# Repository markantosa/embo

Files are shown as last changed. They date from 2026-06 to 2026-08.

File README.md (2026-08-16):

# EMBO — Embolization Particle Sizing System

> SUTD 30.007 Engineering Design Innovation | Team EMBO | Week 13 of 13

EMBO is a closed-loop medical device that automates and quality-controls the preparation of gelatin foam embolic agents for interventional radiology procedures. It is the first device of its kind to measure and control particle size during embolic agent preparation in real time.

| | |
|:---:|:---:|
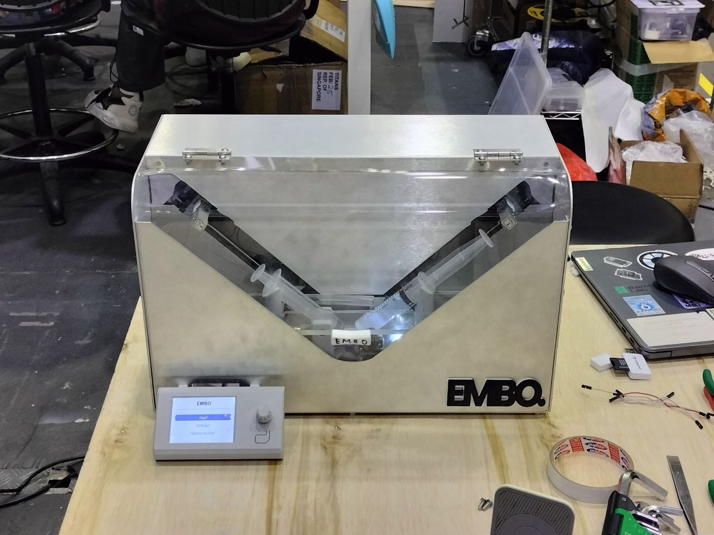
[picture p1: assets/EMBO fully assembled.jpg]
EMBO fully assembled
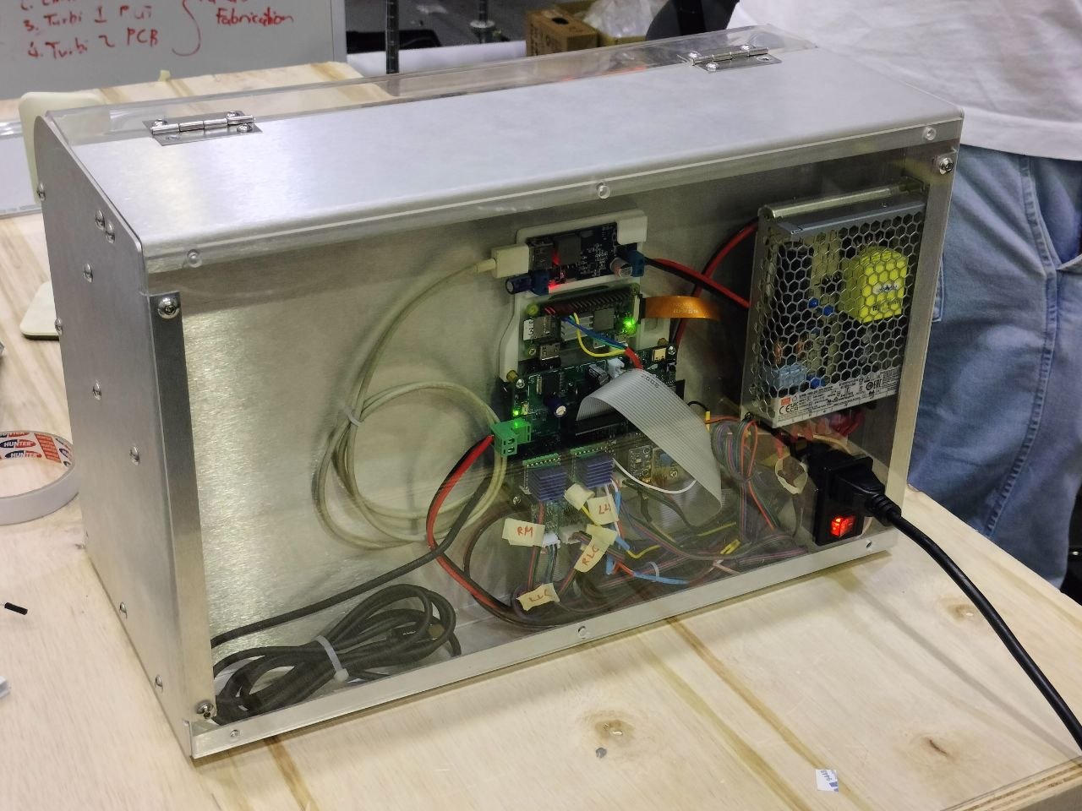
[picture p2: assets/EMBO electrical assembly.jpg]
EMBO electrical assembly
|  |  |
| *Fully assembled device* | *Electrical assembly* |

**CAD renders**

| Isometric | Front | Sheet-metal enclosure |
|:---:|:---:|:---:|
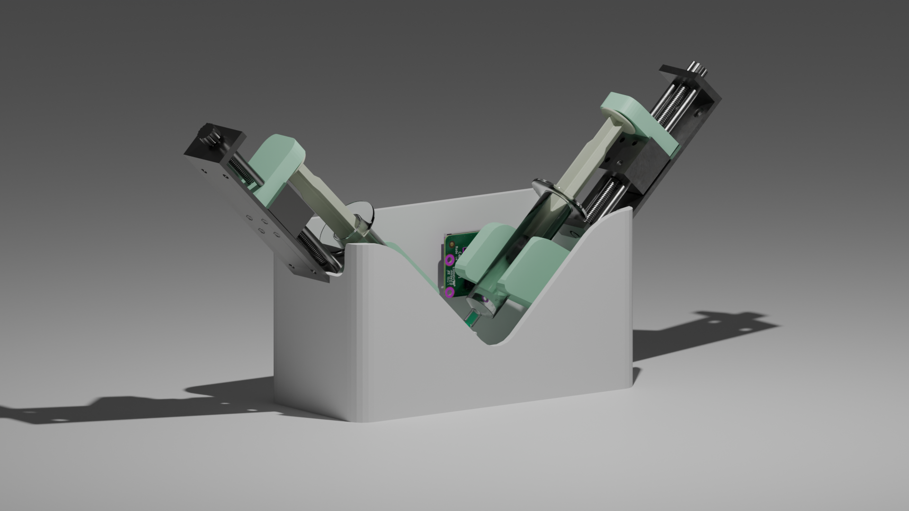
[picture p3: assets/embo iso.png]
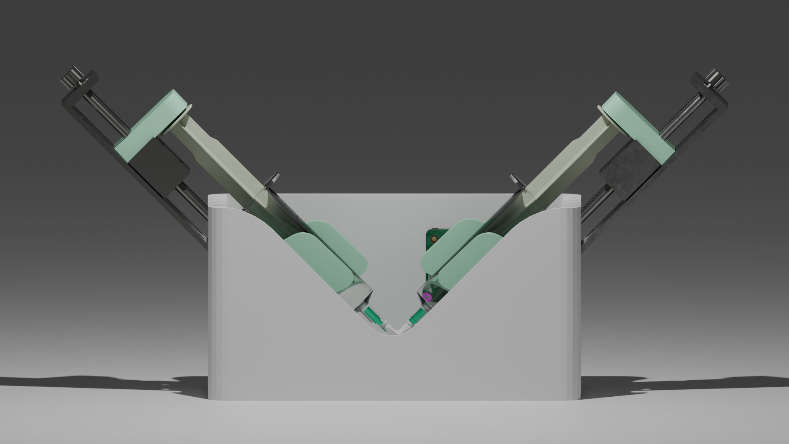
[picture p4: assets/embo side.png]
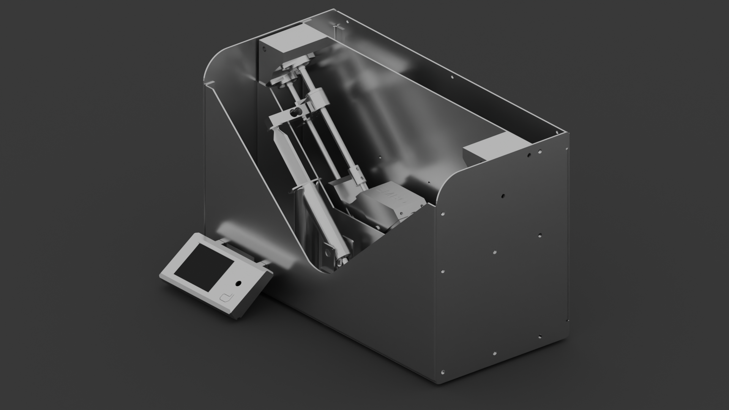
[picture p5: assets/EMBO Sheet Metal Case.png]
|  |  |  |
| *First concept render (Blender)* | *First concept render (Blender)* | *CAD (Fusion 360)* |

---

## The Problem

Embolization procedures use tiny gelatin foam particles (embolic agents) to deliberately block blood vessels — treating tumours, fibroids, and bleeding. Before every procedure, a clinician manually prepares a particle slurry by pumping two syringes back and forth until the mixture reaches a "pudding consistency." There is no measurement, no standard, and no quality check. Two clinicians doing this side by side produce slurries with completely different particle size distributions. Particle size directly affects clinical outcomes: wrong sizes can cause tissue death in unintended areas or fail to block the target vessel.

**No device currently exists to measure or control particle size during this preparation step.** Gelfoam has been used since the 1970s with the preparation method unchanged.

---

## What EMBO Does

EMBO replaces manual syringe pumping with a controlled, sensor-guided system that:

1. **Automates mixing** — two stepper motors drive syringe plungers back and forth with precise speed, stroke, and cycle control
2. **Measures particle size** using two independent sensing modalities:
   - **Ultrasound attenuation (UAS)** — a 1 MHz acoustic signal chain measures how much sound energy the slurry absorbs; larger particles attenuate more. This is the **closed-loop** measurement the mixing stop condition actually runs on.
   - **Computer vision (verification only)** — a Raspberry Pi Zero 2W + OV9281 global-shutter mono camera captures a frame on demand and runs it through a Roboflow-hosted instance-segmentation model, reporting median particle size and IQR plus a segmentation-blob-annotated photo. This is an **optional, operator-triggered check**, not a continuous control input — see "Sensing System" below for why.
3. **Stops automatically** when the target particle size is reached, using a closed-loop control scheduler on the ESP32-S3 driven by the UAS delta-voltage size equation, adjusting stroke-by-stroke based on live sensor feedback. The target is adjustable per procedure (50–1000 µm, set via the touchscreen/encoder), since the ideal size depends on which vessels are being treated.

---

## System Architecture

```
┌─────────────────────────────────────────────────────────────────┐
│                        EMBO Device                              │
│                                                                 │
│  ┌──────────────────┐          ┌──────────────────────────────┐ │
│  │ Raspberry Pi     │◄─UART──►│     ESP32-S3 MCU Board       │ │
│  │ Zero 2W          │          │                              │ │
│  │  - Roboflow      │          │  - Scheduler control loop    │ │
│  │    hosted CV     │          │    (UAS delta-V closed loop) │ │
│  │    (on-demand)   │          │  - 2× TMC2209 motor drivers  │ │
│  │  - Particle size │          │  - UAS signal chain          │ │
│  │    + annotated   │          │  - ILI9341 TFT UI (LovyanGFX)│ │
│  │    photo         │          │  - BLE debug (NimBLE)        │ │
│  │  - OV9281 CSI    │          │                              │ │
│  │    mono camera   │          │                              │ │
│  └──────────────────┘          └──────────────────────────────┘ │
│           │                             │           │            │
│           ▼                             ▼           ▼            │
│    [Camera + LED]              [Stepper motors] [UAS Transducers]│
│    [Backlight panel]           [Limit switches] [SMA connectors] │
└─────────────────────────────────────────────────────────────────┘
```

### Particle Size Model

Mixing follows first-order breakage kinetics:

```
D(N) = D_min + (D₀ − D_min) × e^(−kN)
```

Where `N` is stroke count, `k` is a shear constant (measured empirically), `D₀` is initial particle size, and `D_min` is the minimum achievable size. The mixing scheduler uses live measurements of `D(N)` (via the UAS delta-V equation) to decide when to stop.

---

## Repository Structure

```
EMBO/
├── README.md
├── .gitignore
│
├── docs/                              # Design documents and briefs
│   ├── EMBO_Project_Overview.md       # Project context — public/general audience
│   ├── EMBO_PCB_Design_Brief_v3_4.txt # Complete electrical design spec (current)
│   ├── EMBO_PCB_Design_Brief_v3_4.docx / .pdf
│   ├── EMBO_PCB_Design_Brief_v2.51.txt# Superseded — kept for reference
│   └── EMBO_Pinout_Cheatsheet.txt     # Quick GPIO and connector reference (being updated for v3.4)
│
├── hardware/
│   ├── electrical/                    # KiCad schematics + PCB layout — 2 boards:
│   │   │                              #   main board (v3.4, current) + display breakout
│   │   └── README.md
│   └── mechanical/                    # CAD files (SolidWorks / Fusion 360)
│                                      #   Final Pure Assembly.f3z is the current top-level assembly
│       └── README.md
│
├── firmware/
│   └── esp32/                         # ESP32-S3 Arduino/C++ firmware (PlatformIO)
│       ├── README.md                  # Flash guide and peripheral notes
│       └── ../FIRMWARE_TODO.md        # Build-up task list + hardware checklist
│
├── software/
│   ├── SOFTWARE_TODO.md               # Original CV pipeline build-up task list (superseded, kept for reference)
│   ├── cv_verify/                     # CURRENT — on-demand CV verification, Pi Zero 2W
│   │   ├── SESSION_HANDOFF.md         # Latest working state, Roboflow wiring, hardware notes
│   │   ├── main.py                    # Request/reply loop: waits for CAPTURE, replies SIZE + annotated IMG
│   │   ├── capture.py / preprocessing.py / link.py / config.py
│   │   └── SETUP.md                   # Pi Zero 2W flash/SSH/dev setup
│   └── cv-pipeline/                   # Legacy — original continuous-loop design, Pi 5 + YOLOv8.
│       │                              # detection.py/sizing.py now live here and are imported by
│       │                              # cv_verify/main.py (loop-agnostic), but the driving loop itself
│       │                              # moved to cv_verify/ — see cv_verify/TODO.md for why.
│       └── README.md
│
├── testing/
│   ├── PCB_Test_Firmware_v3_4/        # v3.4 bench-test firmware + Web Bluetooth sensor dashboard
│   └── CV_Verify_UART_Prototype/      # Throwaway prototype that proved out the IMG-over-UART
│                                      # protocol ahead of real detection/sizing existing — since
│                                      # merged into firmware/esp32/ directly, kept for reference
│
└── assets/                            # Images, diagrams, photos
```

Note: TFT touchscreen UI code lives in `firmware/esp32/src/ui.cpp` and is tracked in `firmware/FIRMWARE_TODO.md` — there's no separate `software/ui/` folder, since that code only runs on the ESP32, not the Pi.

---

## Hardware Overview

### Main MCU Board (ESP32-S3) — v3.4

| Subsystem | Components |
|---|---|
| Microcontroller | ESP32-S3-WROOM-1-N4 (4MB flash, no PSRAM, BLE 5.0, USB-C native programming) — corrected from N8 in v3.3, no pinout impact |
| Motor drivers | 2× MKS TMC2209 V2.0 plug-in modules in 2×8 sockets, field-replaceable; MS1/MS2 jumpers (new v3.4) make both modules interchangeable across UART addresses |
| Ultrasound signal chain | AD9833 DDS → OPA2354 Tx (G=4.9, 2.96Vpp) → transducer → OPA2354 Rx (G=100, interstage AC-coupled) → BAT54 envelope → GPIO1 ADC |
| Turbidity sensing | APDS9960 (I2C 0x39, ALS transmission) + MAX30102 (I2C 0x57, backscatter), shared I2C bus |
| Force sensing | 2× load cell + HX711 amplifier, socketed, shared-clock bit-bang driver — hardware fallback for StallGuard SG_RESULT |
| Display | ILI9341 SPI TFT + XPT2046 resistive touch via 20-pin IDC ribbon to breakout board |
| Power | 24V PSU → F1 (off-board T5A fuse) → F2 (on-board 8A backstop, new v3.4) → AO4407A reverse polarity protection → LM2596 buck (5V) → AMS1117 LDO (3.3V) |
| Comms | UART2 to Raspberry Pi (921600 baud, GPIO47/48); BLE UART debug stream (NimBLE) |

v3.4 is a hardware-hardening pass: 12× 220Ω GPIO protection resistors on every ESP32-to-TMC2209 control line (added after a hot-swap/spark incident on the fabricated v2.51 board), the PDN_UART pin correction (module pin 5, not pin 4), and a full reference-designator naming pass. See [`hardware/electrical/README.md`](hardware/electrical/README.md) for the complete changelog.

| | | |
|:---:|:---:|:---:|
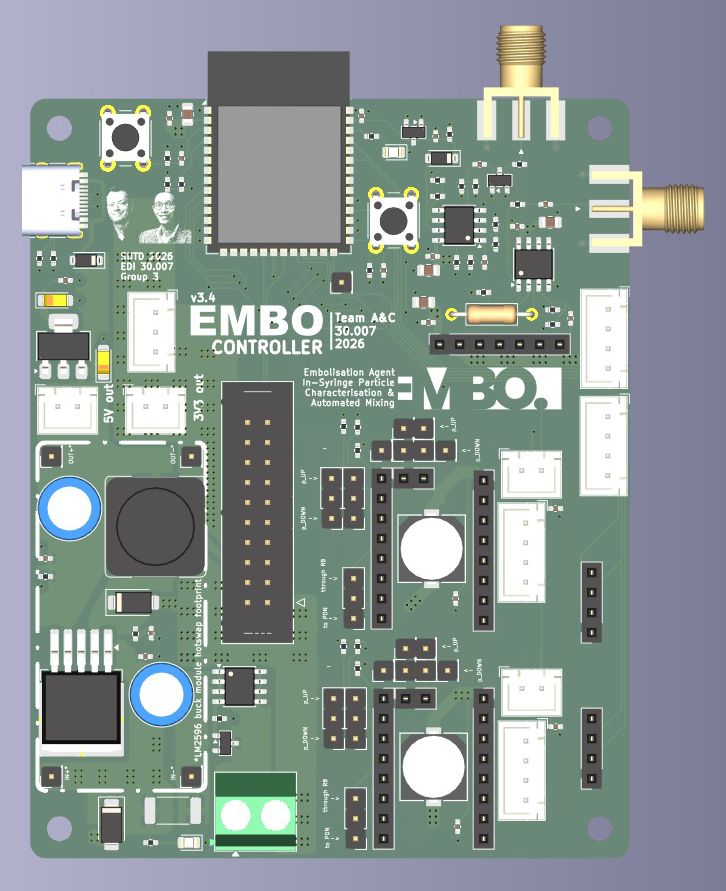
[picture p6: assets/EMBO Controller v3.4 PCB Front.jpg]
v3.4 PCB front render
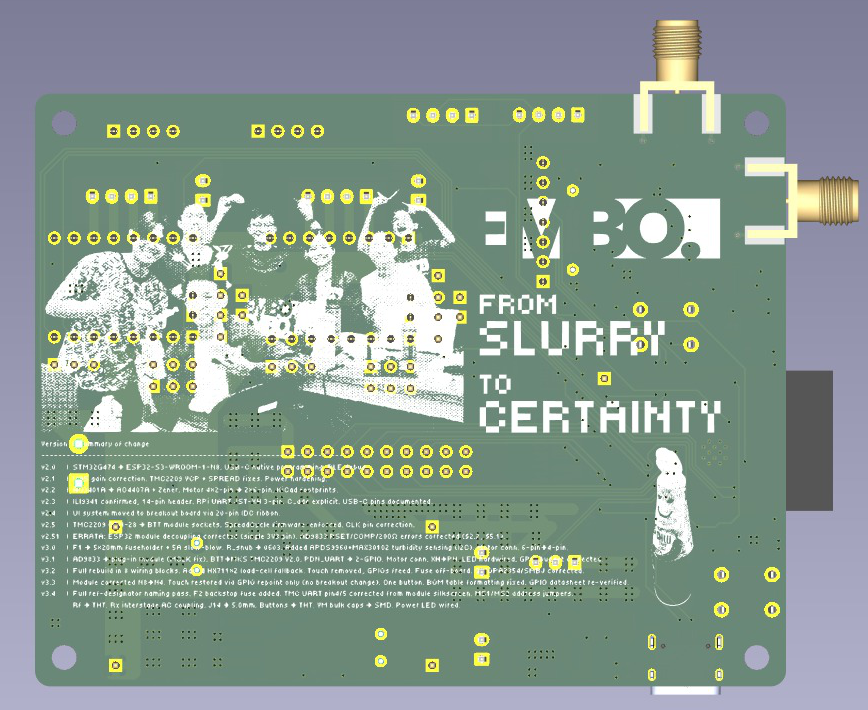
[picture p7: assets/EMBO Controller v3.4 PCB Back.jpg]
v3.4 PCB back render
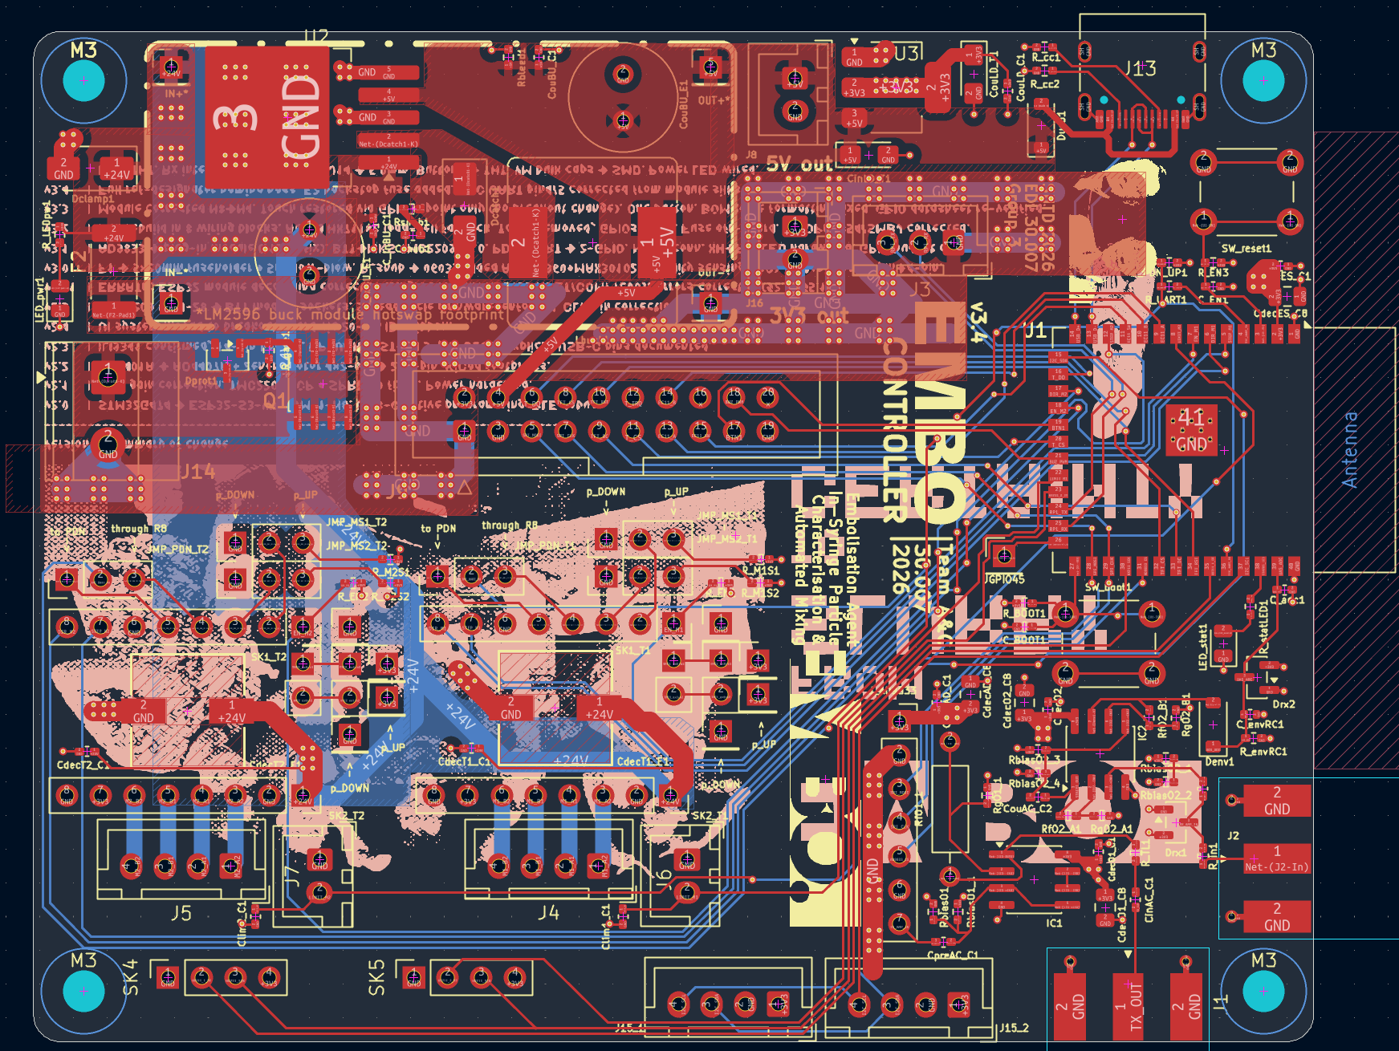
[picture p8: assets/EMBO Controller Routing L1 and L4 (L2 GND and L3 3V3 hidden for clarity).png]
v3.4 PCB trace routing, layers 1 and 4
|  |  |  |
| *3D render, front* | *3D render, back* | *KiCad trace routing — L1 + L4 (L2 GND, L3 3V3 hidden for clarity)* |

| | |
|:---:|:---:|
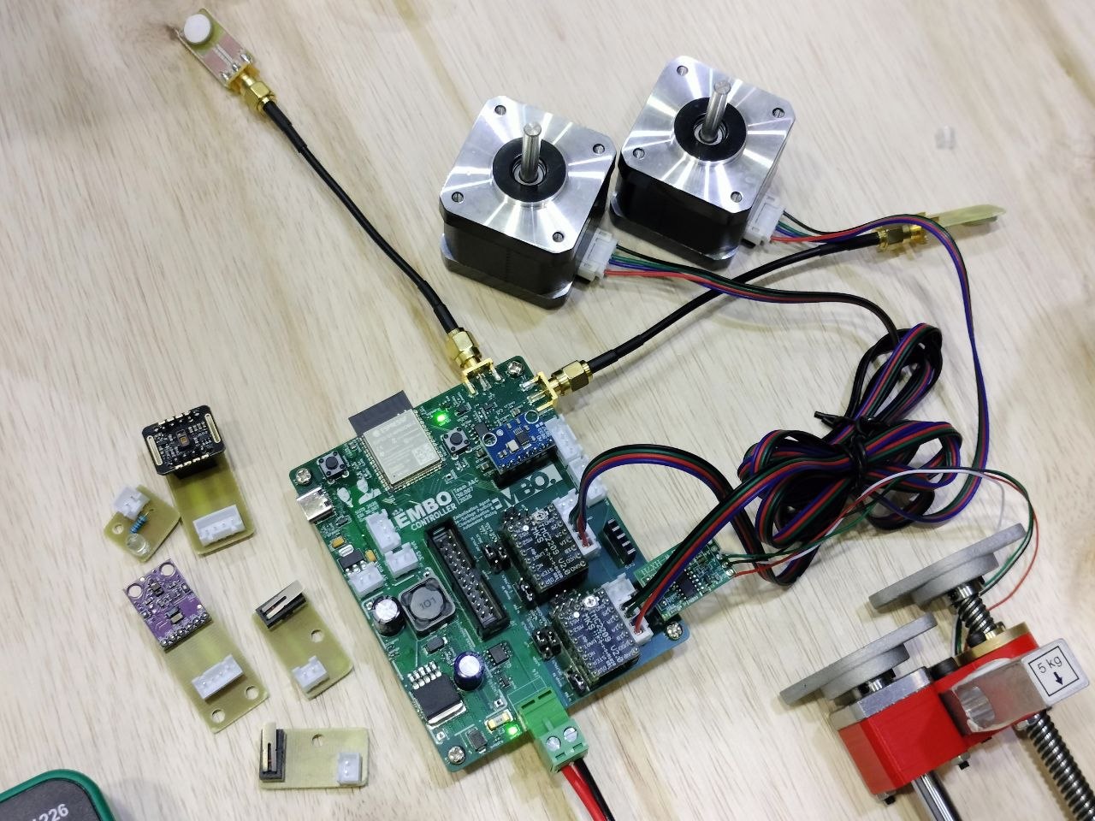
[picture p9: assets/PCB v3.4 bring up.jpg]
v3.4 PCB bring-up
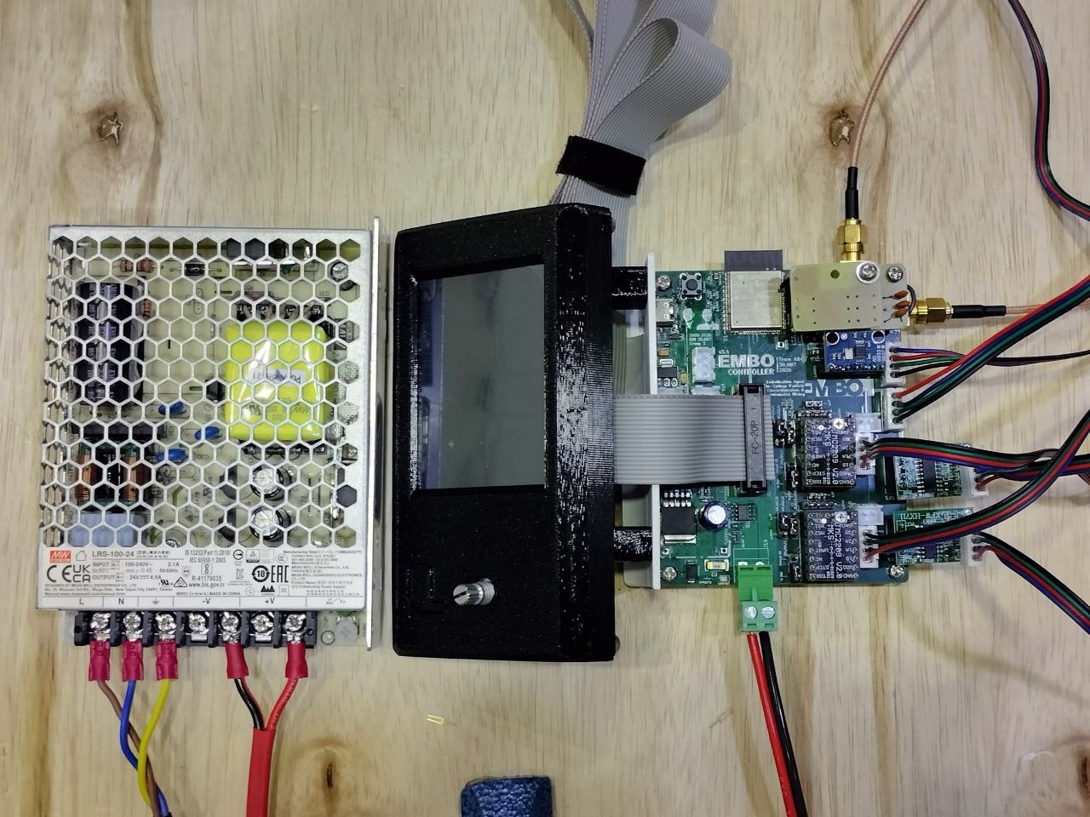
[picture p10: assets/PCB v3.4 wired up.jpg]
v3.4 PCB wired up
|  |  |
| *Fabricated board — bring-up* | *Fabricated board — wired up* |

### GPIO Assignments (key signals)

| GPIO | Signal | Notes |
|---|---|---|
| 1 | UAS_ADC | ADC1_CH0 — envelope detector output |
| 3/43 | I2C_SDA/SCL | Shared bus, APDS9960 (0x39) + MAX30102 (0x57), 400kHz |
| 4/44 | TMC_UART TX/RX | Half-duplex, shared PDN bus, via 1kΩ + 220Ω GPIO protection per module |
| 5/8 | STEP_M1/M2 | Hardware timer — step pulse generation, 220Ω GPIO protection |
| 6/9 | DIR_M1/M2 | Motor direction, 220Ω GPIO protection |
| 7/10 | EN_M1/M2 | Motor enable (active LOW, 10kΩ pull-up at IC), 220Ω GPIO protection |
| 14/15 | LIMIT_M1/M2 | Limit switch inputs (internal pull-up) |
| 19/20 | USB D−/D+ | Fixed USB PHY — no UART bridge chip needed |
| 21/37/42 | HX711_2_DT / SCK (shared) / HX711_1_DT | 2× load cell amplifiers, shared clock |
| 35/36 | SPI MOSI/CLK | Shared: AD9833 (Mode 2) + ILI9341 + XPT2046 (Mode 0) |
| 47/48 | RPi TX/RX | UART2 to Raspberry Pi, 921600 baud |

### Display Breakout Board — 2-layer PCB

ILI9341 TFT + XPT2046 touch controller on a separate board, connected to the main MCU board via a 20-pin IDC ribbon.

| | |
|:---:|:---:|
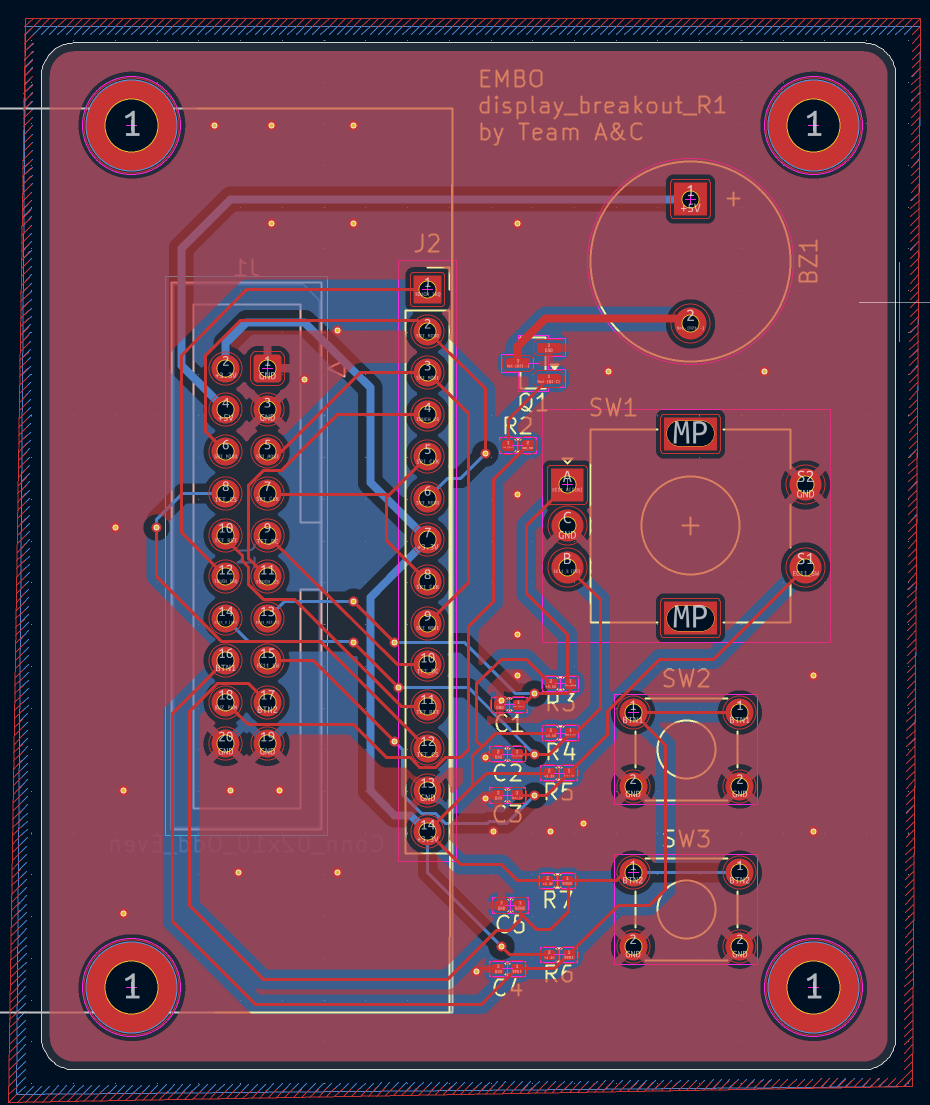
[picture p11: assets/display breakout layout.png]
Display breakout layout
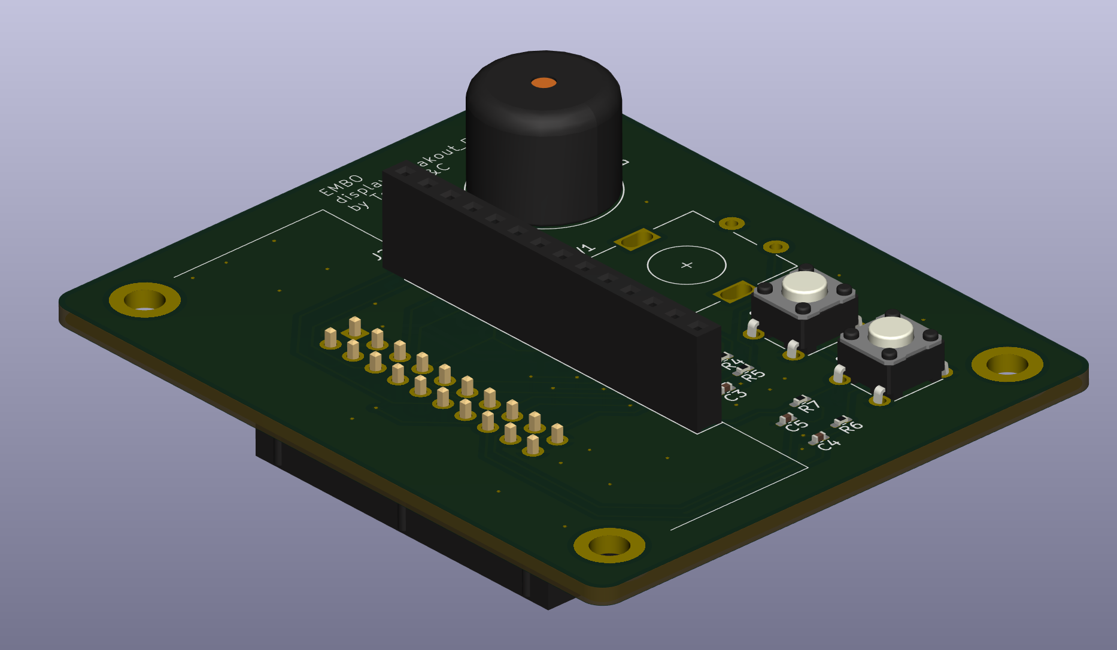
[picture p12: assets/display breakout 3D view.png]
Display breakout 3D view
|  |  |
| *PCB layout* | *3D render* |

### Sensing System

**Ultrasound Attenuation Sensing (UAS):**
- AD9833 generates 1 MHz sine wave → OPA2354 Tx amp (G=4.9, 2.96Vpp output) → J1 SMA → transducer
- Received signal → J2 SMA → BAV99 protection → OPA2354 two-stage Rx (10× + 10× = 100× total) → BAT54 envelope detector → GPIO1
- Firmware reads attenuation ratio vs saline baseline to track particle size change

**Computer Vision (verification, not closed-loop control):**
- Raspberry Pi Zero 2W + OV9281-110 global-shutter mono CSI camera — no dye/contrast agent added to the slurry (real medical-device material), so contrast comes entirely from dark-field/oblique illumination and software-side local-contrast enhancement
- Operator-triggered only: the ESP32 sends `CAPTURE` over UART, the Pi captures + median-stacks frames (noise reduction), runs instance segmentation via a Roboflow-hosted model (RF-DETR, trained on ~100 collected samples), and replies with `SIZE <median_um> <iqr_um>` plus a downscaled photo with segmentation blob outlines baked in — both rendered on the touchscreen's Camera Verify screen side by side, with an IN SPEC/OUT OF SPEC check
- **Not a fusion input** — unlike UAS, a CV result never drives the mixing stop condition; worst case for a failed/slow capture is a timeout notice, not a stalled run. See `software/cv_verify/TODO.md` for the full reasoning
- Diffused LED panel (5V, J8) backlit behind syringe for particle contrast

**Turbidity Sensing (added v3.2, hardened v3.4):**
- APDS9960 (I2C 0x39) reads ALS clear-channel transmission through the syringe; external LED hardwired on
- MAX30102 (I2C 0x57) reads backscatter using its own onboard 660/880nm LEDs
- Shared I2C bus (GPIO3/GPIO43, 400kHz); independent of the UAS acoustic path — a second, optical estimate of slurry turbidity
- Live readings viewable on the BLE **Telemetry Dashboard** (`firmware/esp32/web/`) as Optical Sensor 1/2, alongside every other sensor — see "Getting Started" below
- Like CV, not yet part of the mixing stop condition — the fusion calibration table (`calibration.cpp`) is still unfilled placeholder data for every channel, so only UAS drives the closed loop today

**Force Sensing (added v3.2):**
- 2× load cell + HX711 24-bit amplifier at the syringe plunger contact point
- Shared-clock, per-channel data line — custom bit-bang driver (standard HX711 libraries assume one dedicated clock per chip)
- Hardware fallback for TMC2209 StallGuard SG_RESULT if the UART-based reading proves unreliable

---

## Firmware Status

| Module | File | Status |
|---|---|---|
| TMC2209 UART, SpreadCycle, StallGuard | `src/motors.cpp` | ✅ Done |
| LEDC step generation, limit switch ISRs | `src/motors.cpp` | ✅ Done |
| Homing routine + stroke counter | `src/motors.cpp` | ✅ Done |
| AD9833 1MHz DDS, UAS ADC calibration | `src/uas.cpp` | ✅ Done |
| NimBLE wireless debug UART + binary telemetry service | `src/ble_debug.cpp`, `src/ble_binary_telemetry.cpp` | ✅ Done |
| RPi UART: SIZE reply parsing + on-demand IMG (annotated photo) receive | `src/rpi_uart.cpp` | ✅ Done |
| Mixing scheduler: adjustable setpoint (50–1000µm), closed-loop UAS delta-V stop condition | `src/scheduler.cpp` | ✅ Done — replaces the old PID design |
| TFT UI: encoder-driven menus, live verify screen (photo + PSD/IQR), start/stop-estop | `src/ui.cpp`, `src/ui/screens/` | ⚠️ Touch input still stub (encoder-only works) |
| Turbidity sensors (APDS9960 + MAX30102) | `src/turbidity.cpp` | ✅ Done — feeds the BLE Telemetry Dashboard; not yet a fusion input (calibration table unfilled) |

See [`firmware/FIRMWARE_TODO.md`](firmware/FIRMWARE_TODO.md) for the full task list and hardware bring-up checklist, and [`firmware/esp32/README.md`](firmware/esp32/README.md#operational-workflow) for the doctor-facing operational workflow (boot → home → set target → run → stop/e-stop).

---

## Software Stack

| Layer | Platform | Language | Key Libraries |
|---|---|---|---|
| Computer vision (on-demand verification) | Raspberry Pi Zero 2W | Python 3 | picamera2, Pillow, NumPy, `requests` (Roboflow hosted inference — see `software/cv_verify/detection.py`) |
| Firmware / mixing scheduler | ESP32-S3 | C++ (Arduino) | TMCStepper, NimBLE, LovyanGFX, AD9833 |
| Touchscreen UI | ESP32-S3 | C++ | LovyanGFX |
| BLE debug + telemetry | ESP32-S3 | C++ | NimBLE |

**Critical firmware notes:**
- SPI2 is shared between AD9833 (Mode 2, ~10MHz), ILI9341 (Mode 0, 20MHz max via ribbon), and XPT2046 (Mode 0, 2MHz). Each library switches mode per transaction via `SPI.beginTransaction()`.
- TMC2209 uses a half-duplex UART bus (GPIO4 TX / GPIO44 RX as of v3.4). Raspberry Pi uses UART2 (GPIO47/48). These are separate peripherals — do not reassign.
- ADC1 (GPIO1) is safe while BLE is active. ADC2 cannot be used for analog during BLE — no ADC2 pins are used for analog in this design.
- SpreadCycle must be written via UART to both TMC2209 modules at every boot (no SPREAD pin on the MKS V2.0 modules). BLE log confirms success.
- HX711 reads are pinned to core 1 and short-critical-sectioned — PD_SCK must never sit HIGH past ~60µs or the chip powers itself down mid-read.

---

## Team Structure

| Sub-team | Responsibilities | Members |
|---|---|---|
| **Mechanical** | Frame, syringe holders, motor mounts, 3D printed enclosure (FDM + SLA resin), DOE (Design of Experiments) | Alvin, Victoria, Tian Wen |
| **Electrical & Software** | KiCad schematics + PCB layout (main board + display breakout), component sourcing, board bring-up/testing, ESP32-S3 firmware (mixing scheduler, motor control, UAS), RPi CV verification pipeline (Roboflow), TFT UI | Vincent, Ren Jie, Audrey, Aditi |

---

## Project Timeline

| Milestone | Week | Status |
|---|---|---|
| System Requirements Review | 5 | ✅ Complete |
| Recess week — build sprint | 7 | ✅ Complete |
| PCB schematic freeze | End of 7 | ✅ Complete |
| System Design Review | 9 | ✅ Complete |
| Final Exhibition | 13 | ✅ Current |

---

## Getting Started

### Firmware (ESP32-S3)

Requires VS Code + PlatformIO extension. See [`firmware/esp32/README.md`](firmware/esp32/README.md) for the full flash guide.

```bash
# Quick start
cd firmware/esp32
pio run --target upload   # build and flash
pio device monitor        # serial monitor at 115200
```

Hold `BOOT` + press `RESET` for manual bootloader entry if auto-reset fails.

### Computer Vision Pipeline (Raspberry Pi Zero 2W)

```bash
cd software/cv_verify
python3 -m venv .venv --system-site-packages   # --system-site-packages: sees apt-installed picamera2
source .venv/bin/activate
pip install -r ../requirements.txt
export ROBOFLOW_API_KEY=<your key>             # not stored in any committed file
python3 main.py
```

See [`software/cv_verify/SETUP.md`](software/cv_verify/SETUP.md) for full Pi Zero 2W bring-up (camera/UART dtoverlays, etc.) and [`software/cv_verify/SESSION_HANDOFF.md`](software/cv_verify/SESSION_HANDOFF.md) for current working state and known issues.

### Electrical

PCB files live in `hardware/electrical/` — two boards: the main board (`embo main MCU PCB v3_4/`, current revision) and the display breakout. Open with KiCad 10. The full design spec including component values, GPIO assignments, layout rules, BOM, and the pre-submission checklist is in [`docs/EMBO_PCB_Design_Brief_v3_4.txt`](docs/EMBO_PCB_Design_Brief_v3_4.txt).

### Telemetry Dashboard (real firmware)

`firmware/esp32/web/index_logging to record UAS csv data.html` is a Web Bluetooth dashboard for the actual production firmware (not the bench-test project below) — live UAS envelope, both load cells, and both optical/turbidity sensors (labeled Optical Sensor 1/2), plus motor jog/home controls and the automated UAS frequency sweep. Requires BLE to be enabled on-device first (**Settings → Developer mode → UAS debug mode**), and must be served over http(s) — Web Bluetooth silently fails under a `file://` URL:

```bash
cd firmware/esp32/web
python3 -m http.server 8000
# open http://localhost:8000/index_logging%20to%20record%20UAS%20csv%20data.html
```

### PCB Bench-Test Firmware + Dashboard

`testing/PCB_Test_Firmware_v3_4/` is a separate, standalone PlatformIO project for bringing up an assembled v3.4 board pre-final-firmware: reads every sensor (UAS envelope, both load cells, both turbidity channels, both StallGuard results, limit switches), drives the two steppers, and streams it all over BLE to its own Web Bluetooth dashboard (`web/index.html`) with live strip-charts alongside the raw numbers.

---

## Key References

- Yamagami et al., *The Size of Gelatin Sponge Particles*, CardioVascular and Interventional Radiology, 2006
- Yamamoto et al., CVIR 1997 — liver necrosis vs particle size
- PMC8670118 — hemorrhoidal embolization outcomes
- TMC2209 Datasheet — StallGuard4, SpreadCycle, UART addressing
- AD9833 Datasheet — DDS signal generator, SPI Mode 2
- OPA2354 Datasheet — 250MHz GBW dual op-amp, single-supply operation
- HX711 Datasheet (Avia Semiconductor) — 24-bit ADC, load-cell amplifier
- APDS-9960 Datasheet (Broadcom) — ALS/gesture/proximity sensor
- MAX30102 Datasheet (ADI/Maxim) — pulse oximetry / heart-rate, used here in backscatter mode

---

*SUTD 30.007 Engineering Design Innovation — Team EMBO — 2026*

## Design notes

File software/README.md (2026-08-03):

# Software — Computer Vision Pipeline (Raspberry Pi 5)

Python pipeline that captures images of the gelatin foam slurry through the syringe, runs YOLOv8 inference, and reports particle size statistics to the ESP32-S3 over UART.

See [`../SOFTWARE_TODO.md`](../SOFTWARE_TODO.md) for the full build-up task list, including the optical/lighting and model changes required by the July 2026 technical advisory (`docs/EMBO_UAS_CV_Technical_Advisory.txt`).

New to Raspberry Pi development? See [`RPI_SETUP_GUIDE.md`](RPI_SETUP_GUIDE.md) — flashing the OS, connecting via VS Code Remote-SSH, and hardware bring-up (camera, UART), all from Windows.

## Responsibilities

- Capture frames from an off-the-shelf USB 2.0 microscope camera
- Run YOLOv8 model (trained on gelatin foam particle images) to detect and measure individual particles
- Compute median particle diameter (µm) and IQR per frame
- Transmit statistics to ESP32-S3 over UART (GPIO14/15 on RPi → GPIO47/48 on ESP32-S3, 921600 baud, 3.3V)

## Particle size model

Mixing follows first-order breakage kinetics:

```
D(N) = D_min + (D₀ − D_min) × e^(−kN)
```

The CV pipeline's job is to measure `D(N)` accurately so the PID loop on the ESP32-S3 can compute remaining strokes.

## Setup

```bash
pip install -r requirements.txt
python main.py
```

**Camera:** Raspberry Pi Global Shutter Camera (IMX296, CSI), read through `picamera2`/`libcamera`. Reverted back from an off-the-shelf USB 2.0 UVC microscope camera tried earlier — the UVC camera's rolling shutter produced confirmed motion blur/skew on fast particle movement (see `SOFTWARE_TODO.md` task 12, 3 July 2026 stopcock aperture test notes). Global shutter + a short manual exposure freezes motion instead of relying on strobed illumination. LED backlight panel (powered from PCB J10 at 5V) illuminates the syringe from behind for particle contrast.

**UART:** RPi GPIO14 (TX) → ESP32-S3 GPIO48 (RX), RPi GPIO15 (RX) → ESP32-S3 GPIO47 (TX). Both sides 3.3V — no level shifter required.

**Raspberry Pi power:** Separate USB-C supply. Do not draw power from the UART connector to the PCB.

## Model training

YOLOv8 model trained specifically on gelatin foam particle images. Training data and weights stored separately (see `weights/` — gitignored; obtain from team drive).

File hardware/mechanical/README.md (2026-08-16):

# Mechanical — Frame, Enclosure, and Fixtures

CAD files and fabrication drawings for the EMBO physical structure.

## What lives here

- `Final Pure Assembly.f3z` — current top-level Fusion 360 assembly
- SolidWorks / Fusion 360 assembly and part files
- 3D print files (FDM `.stl`, SLA `.stl`)
- Fabrication drawings

## Device overview

- Metal frame sized to sit on an interventional radiology trolley
- 3D printed (FDM) syringe holder and guide rails
- SLA resin outer cover
- 2× NEMA 17 stepper motors with lead screws — drive syringe plungers
- Mechanical limit switches at each end-of-travel (JST-XH 2-pin to PCB J6/J7)

## Inter-team dependencies

| Decision | Affects |
|---|---|
| Motor selection (torque, frame size) | Electrical: TMC2209 current setting (`irun`); PCB motor connector footprint |
| Lead screw pitch | Firmware: `HOMING_BACKOFF_STEPS` calibration in `config.h`; steps-per-mm for stroke length |
| Syringe holder geometry | Software: camera field of view and working distance |
| Enclosure height clearance | Electrical: BTT TMC2209 plug-in modules + socket stack is taller than original QFN-28 — confirm clearance |
| Enclosure cutouts | Electrical: PCB mounting holes, connector positions (J3 RPi UART, J13 USB-C, J14 PSU, IDC ribbon J9) |

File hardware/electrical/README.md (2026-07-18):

# Electrical — Custom MCU Board

KiCad schematic and PCB layout for the EMBO ESP32-S3 control board.

Current fabricated/in-progress revision: **v3.4** (`hardware/electrical/embo main MCU PCB v3_4/`).
The prior `embo main MCU PCB v2_5/` folder is kept for reference only — see
below for what changed between them.

## Design spec

Full design specification, component values, GPIO assignments, layout rules, BOM, and pre-submission checklist:
[`/docs/EMBO_PCB_Design_Brief_v3_4.txt`](../../docs/EMBO_PCB_Design_Brief_v3_4.txt)

Quick GPIO and connector reference:
[`/docs/EMBO_Pinout_Cheatsheet.txt`](../../docs/EMBO_Pinout_Cheatsheet.txt)
(being updated for v3.4 — treat the design brief above as authoritative in the meantime)

## Quick reference

- **MCU:** ESP32-S3-WROOM-1-N4 (4MB flash, no PSRAM, PCB antenna) — corrected from N8 in v3.3; no pinout impact, flash capacity only affects OTA partitioning
- **Motor drivers:** 2× MKS TMC2209 V2.0 plug-in modules in 2×8 sockets — field-replaceable, MS1/MS2 jumpers make both modules interchangeable across UART addresses 0–3 (new v3.4)
- **Turbidity sensing:** APDS9960 (I2C 0x39, ALS transmission) + MAX30102 (I2C 0x57, backscatter), shared I2C bus
- **Force sensing:** 2× load cell + HX711 amplifier, socketed, shared-clock — hardware fallback for StallGuard SG_RESULT
- **Signal generator:** AD9833 plug-in breakout module (VCC/DGND/SDATA/SCLK/FSYNC/AGND/OUT)
- **Fuse:** 5×20mm slow-blow glass, 5A 250V (T5A), off-board PRIMARY, inline before J14 — **new v3.4:** on-board 8A SMD backstop fuse F2, deliberately rated above F1 so it never coordinates against it
- **Fabrication target:** JLCPCB, 2-layer FR4 ENIG, hot-plate reflow (AD9833/OPA2354 only — TMC2209/HX711 modules are hand-socketed)
- **Schematic tool:** KiCad 10
- **Power rails:** 24V PSU → F1 (off-board) → F2 (on-board backstop) → AO4407A reverse polarity protection → LM2596 buck (5V) → AMS1117 LDO (3.3V)

## v3.4 summary of changes (from v3.3)

This revision is a hardware-hardening and naming-discipline pass, prompted by (a) a live TMC2209 hot-swap incident on the fabricated v2.51 board that sparked and left the ESP32 module overheating on every subsequent power-up, and (b) every passive finally getting an individual reference designator (full lookup table in the design brief §12.3), closing a BOM gap that had gone uncounted.

- **Full reference-designator naming pass** — every resistor, capacitor, diode, the inductor, and both LEDs now has an explicit, unique ref designator
- **On-board backstop fuse F2** — 8A SMD slow-blow (Littelfuse Nano2 452-series), in series after Q1, sized *above* the primary inline T5A so it never coordinates against it; only catches an empty/bypassed/mis-fitted F1 holder
- **TMC2209 UART pin correction** — physical inspection of the MKS V2.0 module's own silkscreen found pin 5 (not pin 4) is the direct PDN_UART node — the opposite of every version through v3.3, which followed generic third-party SilentStepStick documentation instead of this specific module's markings. Jumper default flipped on both U5 and U6.
- **MS1/MS2 address jumpers** — both modules gain 1×3+shunt jumpers on MS1 and MS2 (4 headers total), making U5/U6 fully interchangeable spares instead of hardwired at fixed addresses
- **GPIO short-fault protection** — a 220Ω series resistor on every ESP32-to-TMC2209 control line (STEP, DIR, EN, PDN_UART, MS1, MS2 × 2 modules = 12 resistors), added directly in response to the hot-swap/spark incident on the v2.51 board
- **UAS Tx/Rx hardening** — Tx gain resistor (RfO1_1, 390Ω) changes SMD → THT for field gain adjustment (fixed value, deliberately not a trimpot); Rx chain gains an interstage AC-coupling network ahead of the ×10.1 second stage
- **Component package/procurement changes** — TMC2209 VM bulk caps SMD radial (8mm, beside not under each socket); J14 screw terminal 3.5mm → 5.0mm pitch; boot/reset buttons SMD 6×6 → THT 6mm tactile
- **24V power LED wired** — taps the *protected* rail (Q1 Source), not raw input, so it only lights when Q1 is actually passing current correctly

See the design brief's revision history (§0) for the full v2.0 → v3.4 changelog, and §13 for the pre-submission checklist and open items carried forward from the fabricated v2.51 board (LM2596 buck fault workaround, TMC2209 hot-swap short diagnosis).

## Critical layout rules

- ESP32-S3 antenna keepout: 15mm clear on **all layers** including ground plane
- AMS1117 SOT-223 tab must connect to ≥100mm² copper pour with ≥4 thermal vias
- LM2596 catch diode (SS34A) within 5mm of SW pin, same layer, minimal loop area
- UAS analog traces on top layer only, no vias, routed over uninterrupted ground pour
- C_adc (100nF) within 2mm of GPIO1; C_envRC1 (10nF) distinct component from C_adc
- SK1/SK2: PDN routes to the jumper-selected pin (pin 5 direct = default, pin 4 via on-module R8 = fallback) through its 220Ω GPIO protection resistor — never shunt both jumper positions at once
- All 12 GPIO protection resistors (STEP/DIR/EN/PDN/MS1/MS2 × 2 modules) placed in series at the socket boundary, not upstream at the MCU
- TMC2209 VM bulk caps (100µF SMD radial, 8mm height) placed *beside* each socket, not underneath — clearance for the socket + module stack
- Q1 (AO4407A): Drain → input (J14 side), Source → load (24V rail) — reversed from v3.1, bench-verify ~0mA reverse-polarity draw before trusting the board
- Power off and allow VM bulk caps to fully discharge before inserting/removing any TMC2209 module — procedural rule added after the v2.51 hot-swap/spark incident

## TMC2209 module addressing

MS1/MS2 are field-jumpered as of v3.4 (previously hardwired), making U5 and U6 fully interchangeable spares:

| Driver | Module | MS1 jumper | MS2 jumper | UART address |
|---|---|---|---|---|
| Motor 1 | U5 (SK1) | GND (no shunt) | GND (no shunt) | 0 |
| Motor 2 | U6 (SK2) | 3.3V via 10kΩ (JMP_MS1_T2) | GND (no shunt) | 1 |

Shared half-duplex PDN_UART bus: GPIO4 (TX) / GPIO44 (RX) via R_UART (1kΩ) + R_PDN_UP (10kΩ pull-up to 3.3V), through each module's 220Ω GPIO protection resistor to its jumper-selected pin (pin 5 direct by default, §7.3 of the design brief).

## Screenshots

### Main MCU board — v3.4 (current)

| | | |
|:---:|:---:|:---:|
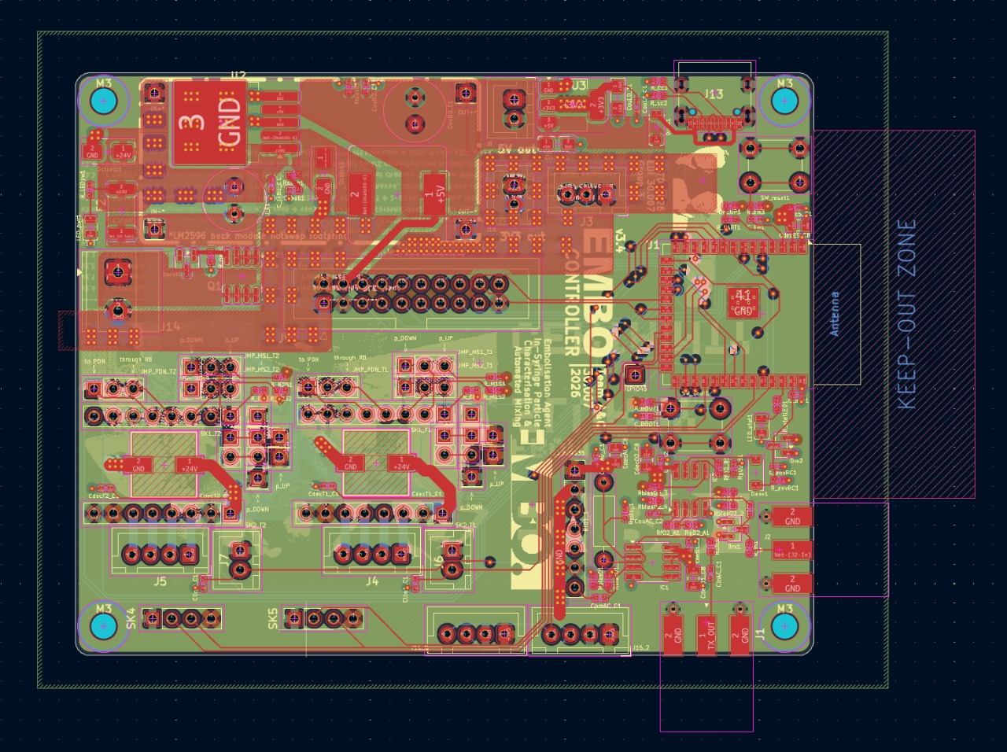
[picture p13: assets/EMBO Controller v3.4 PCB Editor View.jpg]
v3.4 PCB editor view
| v3.4 PCB front | v3.4 PCB back |  |
| *Assembled board, front* | *Assembled board, back* | *KiCad PCB editor view* |

### Main MCU board — earlier render (v2.5)

| | |
|:---:|:---:|
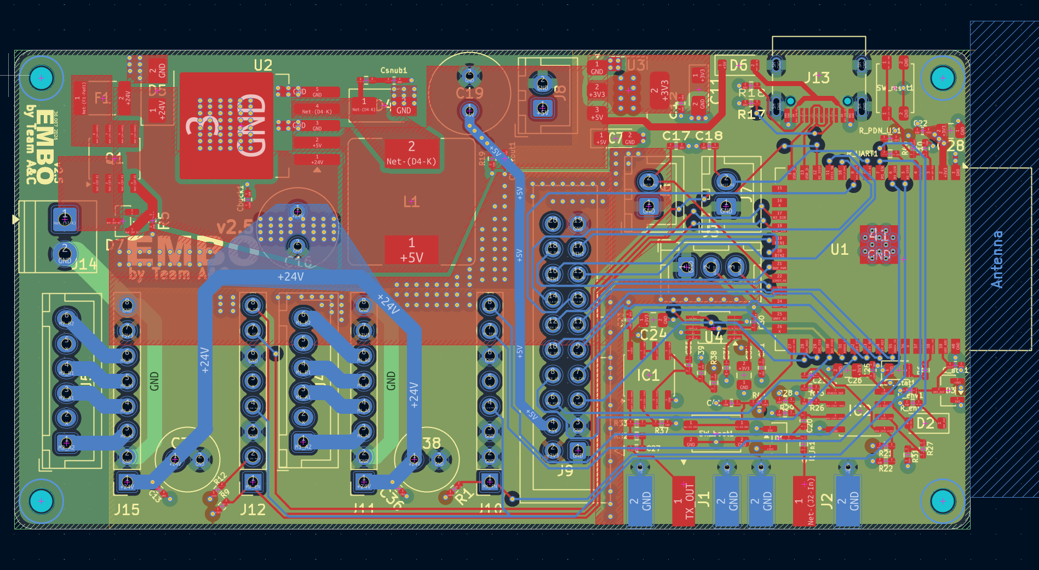
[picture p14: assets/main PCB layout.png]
Main PCB layout
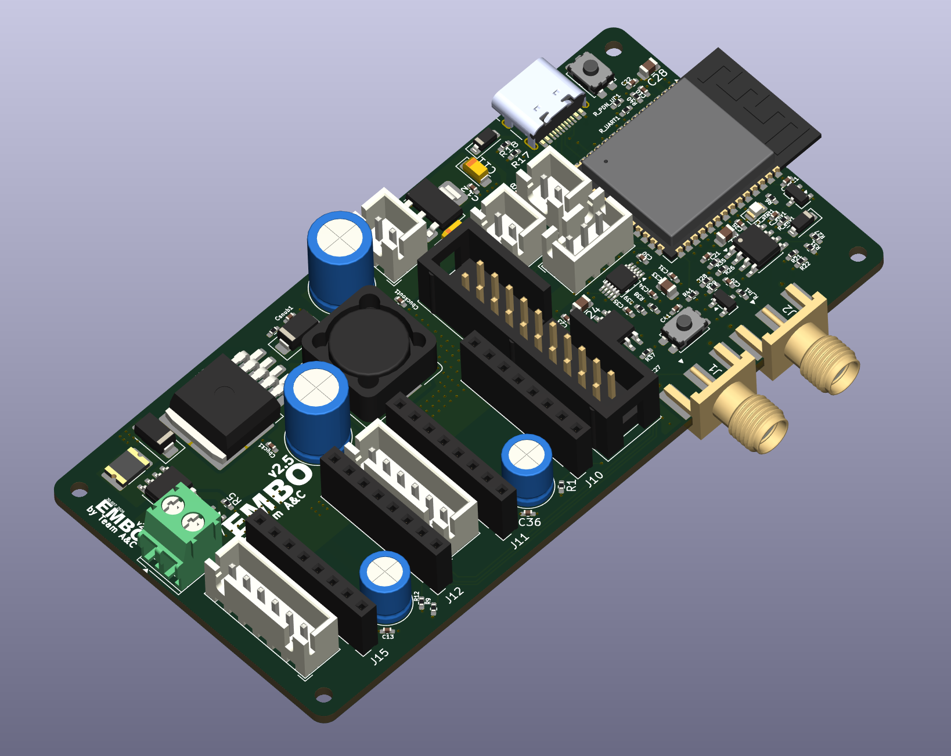
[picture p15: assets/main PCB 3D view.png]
Main PCB 3D view
|  |  |
| *PCB layout* | *3D render* |

### Display breakout board

Pinout and IDC ribbon interface unchanged since v2.4 — carried forward as-is into v3.4.

| | |
|:---:|:---:|
| Display breakout layout | Display breakout 3D view |
| *PCB layout* | *3D render* |

## Firmware bring-up dependency

SpreadCycle cannot be set by hardware (no SPREAD pin on the MKS V2.0 modules). Firmware **must** write `GCONF.en_spreadcycle=1` to both drivers at every boot and read back to confirm before trusting StallGuard data. See [`firmware/FIRMWARE_TODO.md`](../../firmware/FIRMWARE_TODO.md) for the full hardware bring-up checklist, and [`testing/PCB_Test_Firmware_v3_4/`](../../testing/PCB_Test_Firmware_v3_4/) for the v3.4 bench-test firmware and Web Bluetooth sensor dashboard.

## Open items (carried forward from the fabricated v2.51 board)

- **LM2596 (U2) buck fault** — external buck module workaround in place; U2 itself never bench-verified standalone
- **TMC2209 hot-swap short** — the ESP32 module is suspected damaged from the v2.51 hot-swap/spark incident; diagnosis in progress (unpowered 3V3-to-GND resistance check, ESP32 isolation)
- **AD9833 real output amplitude** — never measured on a scope; every UAS gain figure in the design brief rests on the datasheet-typical ~0.6Vpp, not a confirmed measurement

## Schematic status

v3.4 is a full rebuild in 8 wiring blocks (per team request) — see the design brief for the pre-submission checklist (§13) before sending to fab.

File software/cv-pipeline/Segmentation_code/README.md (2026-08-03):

# Classical CV Particle Segmentation — Salt Calibration Test

## Purpose
Before running this pipeline on real Gelfoam/embolic agent samples, it was
validated on **table salt** as a known, easy-to-segment reference material.
Salt grains are opaque, high-contrast, and roughly uniform — a good sanity
check to confirm the capture → threshold → detect → measure pipeline works
correctly and the calibration factor is sound, before trusting it on harder
(translucent, irregular) real material.

## Method
- **Hardware:** Raspberry Pi 5 + camera module, running `picamera2` directly
  (no CLI capture tool — sidesteps intermittent `rpicam-still` capture bugs).
- **Calibration:** pixel-to-micron conversion factor determined from a ruler
  photograph at the same capture resolution: **`UM_PER_PIXEL = 14.34`**.
- **Segmentation approach:** classical (non-AI) computer vision —
  1. Convert to grayscale, Gaussian blur
  2. **Adaptive thresholding** (not a single global/Otsu threshold) — compares
     each pixel to its local neighborhood brightness, which was necessary
     because lighting was not perfectly even across the frame. A global
     threshold initially merged particles into large false blobs; switching
     to adaptive thresholding fixed this.
  3. Contour detection on the resulting binary mask
  4. Size filtering (contours <15px² treated as noise/dust; >8000px² treated
     as merged/touching particles and excluded)
  5. **Ellipse fitting** per contour (not a circle fit) to account for
     irregular, non-circular particle shapes; major axis length is converted
     to microns using the calibration factor
  6. Aggregate all detected particles across multiple captures into a
     combined median + IQR

No trained model or AI is involved in this pipeline — every step is a fixed,
deterministic image-processing operation.

## Results (salt)
| Metric | Value |
|---|---|
| Total particles detected | 750 |
| Median size | 215 µm |
| IQR | *(see console output for exact Q1/Q3/IQR/min/max — not visible in the histogram screenshot alone)* |

This is a plausible, sensible size range for fine table salt, indicating the
capture pipeline, thresholding fix, and calibration factor are all working
correctly together — this result served as the go/no-go check before moving
to real Gelfoam material testing.

**Calibration check** — ruler tick spacing measured at ~69.5–70.0 px between
1 mm marks, consistent with the `UM_PER_PIXEL = 14.34` calibration factor
used in the script (1000 µm / ~69.75 px ≈ 14.34).

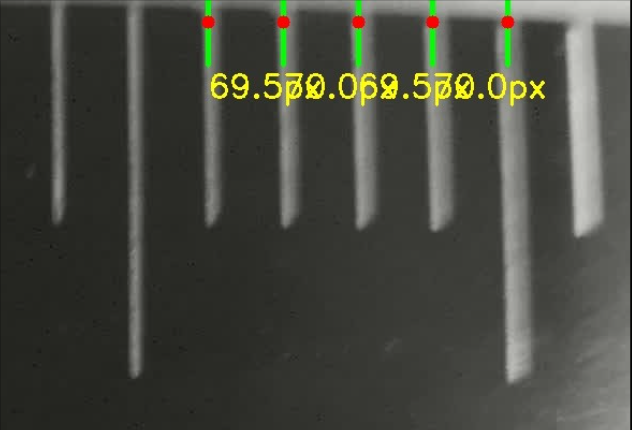
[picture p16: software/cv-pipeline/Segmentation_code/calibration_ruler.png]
Ruler calibration check


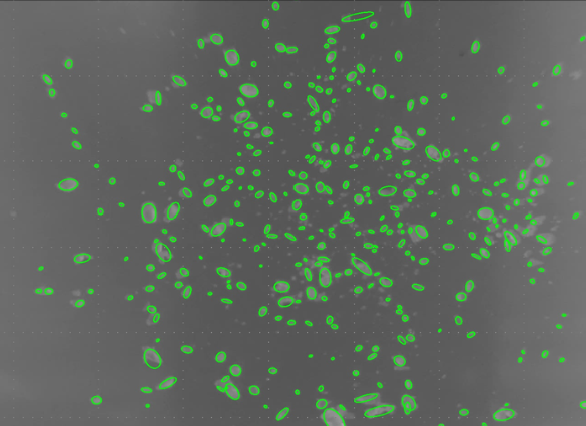
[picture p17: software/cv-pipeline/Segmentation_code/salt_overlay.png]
Detected salt particles with ellipse fit overlay


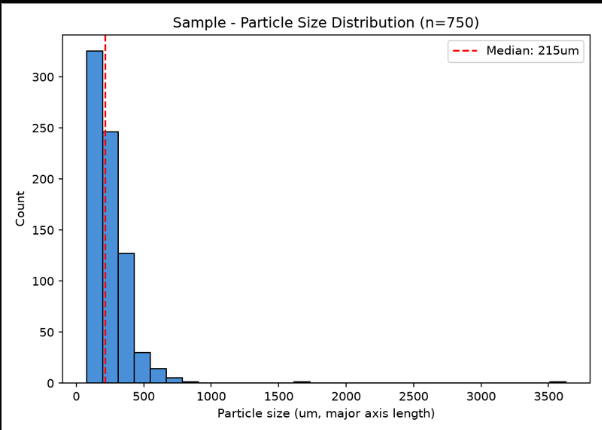
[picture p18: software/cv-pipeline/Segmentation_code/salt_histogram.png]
Salt particle size distribution histogram


## Files
- `capture_and_analyze.py` — the script itself. Captures `NUM_SHOTS` images
  directly from the Pi camera (prompting between each so the sample can be
  repositioned/respread), detects and measures particles in each, and prints
  + plots the combined summary statistics.
- `images/calibration_ruler.png` — ruler shot used to confirm the pixel-to-
  micron calibration factor before trusting particle measurements.
- `images/salt_overlay.png` — detected particles (green ellipse fits) on a
  salt sample frame.
- `images/salt_histogram.png` — resulting particle size distribution
  (n=750, median 215 µm).

## Known limitations
- Adaptive threshold parameters (block size 101, C=-15) were tuned for this
  specific lighting setup and camera distance — they are not guaranteed to
  generalize to different lighting conditions without re-tuning.
- Ellipse-fit major axis is used as the reported "size" here, which is closer
  to a Feret-diameter-style measurement rather than the equivalent circular
  diameter (ECD) convention used elsewhere in this project's later
  microscope-based measurements — noted here for consistency awareness when
  comparing across datasets.
- This pipeline has not been validated against translucent/low-contrast
  material (e.g. real Gelfoam surrogate) with the same accuracy as shown here
  for salt; see project documentation for status on that testing track.

## How to run
```bash
# on the Raspberry Pi
sudo apt install -y python3-picamera2   # if not already installed
python3 capture_and_analyze.py
```
Follow the on-screen prompts to position and capture each sample. Results
print to the console and save as image/plot files in the working directory.

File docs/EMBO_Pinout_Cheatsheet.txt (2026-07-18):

================================================================
EMBO — PINOUT CHEAT SHEET  (v3.4, ESP32-S3-WROOM-1-N4)
================================================================
Quick reference only. Full spec, rationale, and pre-submission checklist:
docs/EMBO_PCB_Design_Brief_v3_4.txt

CHANGED SINCE v2.4 (do not wire from memory — several GPIOs below now
carry a DIFFERENT signal than the old v2.4 sheet documented):
  - MCU corrected N8 -> N4 (no pinout impact, flash size only)
  - GPIO21, GPIO37, GPIO42 previously carried touch signals; they are now
    HX711 load-cell pins (added v3.2). Touch was relocated in v3.3 to
    GPIO12 (T_CS) / GPIO46 (T_DO); T_IRQ is NOT connected (polled instead).
  - TMC UART is now two separate pins, GPIO4 (TX) + GPIO44 (RX), not one
    bidirectional pin on GPIO4.
  - PDN_UART target pin on the MKS V2.0 module corrected v3.4: pin 5
    (direct), NOT pin 4 — opposite of every version through v3.3.
  - Motor connectors J4/J5 changed JST-XH 6-pin -> JST-PH 4-pin.
  - PSU input J14 changed 3.5mm -> 5.0mm screw terminal; on-board 8A
    backstop fuse F2 added (v3.4) after the off-board 5A T5A fuse F1.
  - TMC2209 MS1/MS2 address straps are now field jumpers, not hardwired.
  - Turbidity (I2C, GPIO3/43) and force sensing (HX711, GPIO21/37/42)
    added v3.2, both still present and hardened in v3.4.
  - 12x 220R series resistors added v3.4 on every ESP32-to-TMC2209
    control line (STEP/DIR/EN/PDN/MS1/MS2 x2) — GPIO-side short-fault
    protection, added after a hot-swap/spark incident on the fabricated
    v2.51 board. Electrically transparent (see design brief §7.6) but
    physically present in the signal path — don't probe past them and
    assume a dead short is at the GPIO itself.

----------------------------------------------------------------
1. ESP32-S3 GPIO ASSIGNMENTS
----------------------------------------------------------------

GPIO  Signal          Dir    Connected to
----  --------------  -----  ----------------------------------------
0     BOOT            Strap  R_BOOT/C_BOOT/SW_boot (THT tactile, v3.4)
1     UAS_ADC         In     Envelope detector output (ADC1_CH0)
2     STATUS_LED      Out    330Ω → green LED (LED_stat) → GND
3     I2C_SDA         Bidir  J15 pin3 (turbidity) — 4.7kΩ pull-up to 3.3V. Strapping (JTAG src) — benign, see brief §6.5
4     TMC_UART_TX     Out    R_UART(1kΩ) → shared PDN bus → jumper-selected module pin (5 default)
5     STEP_M1         Out    TMC2209 U5 STEP, via 220Ω GPIO protection (R_gpSTEP_T1)
6     DIR_M1          Out    TMC2209 U5 DIR, via 220Ω GPIO protection (R_gpDIR_T1)
7     EN_M1           Out    TMC2209 U5 EN (10kΩ pull-up at IC), via 220Ω GPIO protection (R_gpEN_T1)
8     STEP_M2         Out    TMC2209 U6 STEP, via 220Ω GPIO protection (R_gpSTEP_T2)
9     DIR_M2          Out    TMC2209 U6 DIR, via 220Ω GPIO protection (R_gpDIR_T2)
10    EN_M2           Out    TMC2209 U6 EN (10kΩ pull-up at IC), via 220Ω GPIO protection (R_gpEN_T2)
11    BTN1            In     IDC pin 16 → breakout button 1 (pull-up + debounce on breakout)
12    T_CS            Out    IDC pin 11 → XPT2046 T_CS (touch chip select, restored v3.3 — was BTN2)
13    BUZ_PWM         Out    IDC pin 18 → buzzer (LEDC PWM)
14    LIMIT_M1        In     J6 pin 2 — limit switch 1 to GND, 100nF debounce (Clim1_C1)
15    LIMIT_M2        In     J7 pin 2 — limit switch 2 to GND, 100nF debounce (Clim2_C2)
16    EC11_A (CLK)    In     IDC pin 13 → EC11 A
17    EC11_B (DT)     In     IDC pin 14 → EC11 B
18    EC11_SW         In     IDC pin 15 → EC11 push switch
19    USB D−          Fixed  USB-C A7 + B7 (fixed PHY — no other use)
20    USB D+          Fixed  USB-C A6 + B6 (fixed PHY — no other use)
21    HX711_2_DT      In     HX711 module #2 (SK5) DOUT — CHANGED v3.2, was TOUCH_IRQ pre-v3.2
35    SPI_MOSI        Out    AD9833 SDATA + IDC pin 5 (TFT/touch) — PSRAM-free module only
36    SPI_CLK         Out    AD9833 SCLK + IDC pin 7 (TFT/touch), 20MHz — PSRAM-free module only
37    HX711_SCK       Out    Both HX711 modules' PD_SCK (shared clock) — CHANGED v3.2, was SPI_MISO/touch pre-v3.2
38    AD9833_CS       Out    AD9833 FSYNC (active LOW, SPI Mode 2)
39    TFT_CS          Out    IDC pin 8 → ILI9341 CS (active LOW)
40    TFT_DC          Out    IDC pin 9 → ILI9341 DC
41    TFT_RST         Out    IDC pin 10 → ILI9341 RESET (active LOW)
42    HX711_1_DT      In     HX711 module #1 (SK4) DOUT — CHANGED v3.2, was TOUCH_CS pre-v3.2
43    I2C_SCL         Out    J15 pin4 (turbidity) — 4.7kΩ pull-up to 3.3V. UART0-TX by default; board uses USB-Serial/JTAG, so free
44    TMC_UART_RX     In     R_UART → shared PDN bus (RX leg) — genuinely separate pin from TX (GPIO4), corrected in this project's bring-up after single-pin UART proved unreliable
45    FREE (strap)    -      SP7 1-pin header, unpopulated — sole remaining spare GPIO. Must read LOW at boot (VDD_SPI select)
46    T_DO            In     IDC pin 6 → XPT2046 T_DO (touch data out, restored v3.3 — was SPI_MISO pre-v3.3). No external pull-up — safe on this strapping pin, see brief §8.3
47    RPi_TX          Out    J3 pin 3 → RPi UART, 921600 baud
48    RPi_RX          In     J3 pin 2 ← RPi UART, 921600 baud

IDC pin 12 (T_IRQ) and pin 17 (BTN2) are NOT CONNECTED on the main board
(touch is polled, one-button UI). Physically present on the ribbon/breakout,
just NC at the main-board connector — see design brief §8.3.

SPI speeds: ILI9341 via ribbon → 20 MHz max | XPT2046 → per chip, lower
            AD9833 direct → ~10 MHz (Mode 2) | TFT/touch → Mode 0
I2C:        400kHz, Wire.begin(SDA=3, SCL=43)

----------------------------------------------------------------
2. EXTERNAL CONNECTORS (MAIN BOARD)
----------------------------------------------------------------

J1  TX Transducer     SMA edge-launch    Centre: IC1 out via R_TL1(47Ω) + CinAC_C1(100nF)
J2  RX Transducer     SMA edge-launch    Centre: R_in(100Ω) → Drx1(BAV99) → IC2
J3  RPi UART          JST-XH 3p 2.5mm    1:GND | 2:RX(GPIO48) | 3:TX(GPIO47), 921600 baud
J4  Motor 1           JST-PH 4p 2.0mm    1:OA1 | 2:OA2 | 3:OB1 | 4:OB2 — CHANGED v3.1, was 6p JST-XH
J5  Motor 2           JST-PH 4p 2.0mm    1:OA1 | 2:OA2 | 3:OB1 | 4:OB2
J6  Limit switch M1   JST-XH 2p 2.5mm    1:GND | 2:GPIO14, 100nF debounce at MCU
J7  Limit switch M2   JST-XH 2p 2.5mm    1:GND | 2:GPIO15, 100nF debounce at MCU
J8  LED panel         JST-XH 2p 2.5mm    1:5V | 2:GND
J9  UI breakout IDC   IDC 2×10 2.54mm    20-pin ribbon (see Section 3)
J13 USB-C programming USB-C receptacle   A6+B6→GPIO20 | A7+B7→GPIO19 | CC1/CC2→5.1kΩ GND
J14 24V PSU input     5.0mm screw 2p     CHANGED v3.4, was 3.5mm. 1:V+ | 2:GND. V+ → F1(off-board T5A) → F2(on-board 8A backstop) → Q1(AO4407A) → 24V rail
J15 Turbidity I2C     JST-XH 4p 2.5mm    1:3.3V | 2:GND | 3:SDA(GPIO3) | 4:SCL(GPIO43)
J16 APDS9960 ext LED  JST-XH 2p 2.5mm    1:LED+ (3.3V via R_LEDext 330Ω) | 2:GND

SK1/SK2  TMC2209 modules (MKS V2.0)   2×8 socket   See Section 7
SK3      AD9833 signal gen module     1×7 socket   VCC/DGND/SDATA/SCLK/FSYNC/AGND/OUT
SK4/SK5  HX711 load-cell amplifiers   1×4 socket   See Section 8

Fuses: F1 off-board 5x20mm 5A 250V T5A slow-blow (in the +24V lead before
J14, PRIMARY protection) + F2 on-board 8A Nano2 452 SMD backstop (between
J14 and Q1 Drain — NOT the primary, silkscreened "BACKSTOP" — see brief §2.1).

----------------------------------------------------------------
3. J9 IDC RIBBON (20-PIN, MAIN <-> UI BREAKOUT) — pinout unchanged since
   original design; only which main-board GPIO lands on each pin changed.
----------------------------------------------------------------
Pin 1 = red stripe. Always GND. Both PCBs: shrouded (box) IDC headers.

Pin  Signal          GPIO / Net  Dir   Notes
---  --------------  ----------  ----  ------------------------------------------
1    GND             —           —     Red stripe reference
2    3.3V            3.3V rail   Out   TFT logic + breakout pull-ups
3    GND             —           —     Extra GND
4    5V              5V rail     Out   Buzzer supply
5    SPI_MOSI        GPIO35      Out   ILI9341 SDI + XPT2046 T_DIN
6    T_DO            GPIO46      In    XPT2046 T_DO — CHANGED v3.3, was GPIO37 pre-v3.2, NC in v3.2
7    SPI_CLK         GPIO36      Out   20 MHz max via ribbon, shared TFT+touch
8    TFT_CS          GPIO39      Out   ILI9341 CS — active LOW
9    TFT_DC          GPIO40      Out   ILI9341 data/command
10   TFT_RST         GPIO41      Out   ILI9341 reset — active LOW
11   T_CS            GPIO12      Out   XPT2046 CS — active LOW — CHANGED v3.3, was GPIO42 pre-v3.2, reused from removed BTN2
12   T_IRQ           NC          —     CHANGED v3.3 — touch is polled, not interrupt-driven. NOT wired on main board
13   EC11_A (CLK)    GPIO16      In    Encoder A
14   EC11_B (DT)     GPIO17      In    Encoder B
15   EC11_SW         GPIO18      In    Encoder push switch
16   BTN1            GPIO11      In    Push button 1
17   BTN2            NC          —     REMOVED v3.3 — one-button UI. Ribbon pin still wired on breakout, NC at main board
18   BUZ_PWM         GPIO13      Out   Buzzer (LEDC PWM)
19   GND             —           —     Extra GND
20   NC              —           —     No connect

----------------------------------------------------------------
4. TFT MODULE (14-PIN SOCKET ON BREAKOUT) — breakout board itself unchanged
----------------------------------------------------------------

Socket  Module label  Signal (from ribbon/net)
------  ------------  ----------------------------------------
1       VCC           Ribbon pin 2 (3.3V)
2       GND           Ribbon pin 1/3/19 (GND)
3       CS            Ribbon pin 8 (TFT_CS / GPIO39)
4       RESET         Ribbon pin 10 (TFT_RST / GPIO41) + 10kΩ pull-up
5       DC            Ribbon pin 9 (TFT_DC / GPIO40)
6       SDI (MOSI)    Ribbon pin 5 (SPI_MOSI / GPIO35)
7       SCK           Ribbon pin 7 (SPI_CLK / GPIO36) — 20 MHz max
8       LED           3.3V via 47Ω on breakout (always-on backlight)
9       SDO (MISO)    Ribbon pin 6 (T_DO / GPIO46) — CHANGED: was GPIO37 pre-v3.2
10      T_CLK         Same net as pin 7 (SCK)
11      T_CS          Ribbon pin 11 (T_CS / GPIO12) — CHANGED: was GPIO42 pre-v3.2
12      T_DIN         Same net as pin 6 (MOSI)
13      T_DO          Same net as pin 9 (MISO / T_DO)
14      T_IRQ         Ribbon pin 12 — NC at main board as of v3.3 (polled instead)

On breakout: tie MOSI→pins 6+12, CLK→pins 7+10, MISO/T_DO→pins 9+13

----------------------------------------------------------------
5. EC11 ROTARY ENCODER (BREAKOUT) — unchanged
----------------------------------------------------------------

EC11 pin  Signal   Ribbon pin  GPIO   Breakout filter
--------  -------  ----------  -----  --------------------
A (CLK)   EC11_A   13          GPIO16  10kΩ pull-up + 100nF
B (DT)    EC11_B   14          GPIO17  10kΩ pull-up + 100nF
SW        EC11_SW  15          GPIO18  10kΩ pull-up + 100nF
COM (×2)  GND      —           —      Tie to GND

----------------------------------------------------------------
6. PUSH BUTTON (BREAKOUT) — one button as of v3.3 (BTN2 removed)
----------------------------------------------------------------

Button  Signal  Ribbon pin  GPIO   Breakout filter
------  ------  ----------  -----  --------------------
BTN1    BTN1    16          GPIO11  10kΩ pull-up + 100nF

BTN2 footprint may still exist on the breakout silkscreen; ribbon pin 17
is left NC at the main board — do not populate a BTN2 connection there.

----------------------------------------------------------------
7. TMC2209 MOTOR DRIVER ADDRESSING (U5 / U6) — MKS V2.0 modules,
   field-jumpered as of v3.4 (was hardwired through v3.3)
----------------------------------------------------------------

Driver   Ref  MS1 jumper (JMP_MS1_Tn)   MS2 jumper (JMP_MS2_Tn)   UART Addr
-------  ---  ------------------------  ------------------------  ---------
Motor 1  U5   GND (no shunt)            GND (no shunt)            0
Motor 2  U6   3.3V via 10kΩ (shunt)     GND (no shunt)            1

Shared half-duplex PDN_UART bus: GPIO4 (TX) + GPIO44 (RX), joined by
R_UART (1kΩ), bus pull-up R_PDN_UP (10kΩ to 3.3V). Each module's PDN pin
is selected by its own 3-pin jumper (JMP_U5 / JMP_U6):
  - Shunt 2-1 (DEFAULT, v3.4): module pin 5, DIRECT — corrected v3.4 after
    physical inspection of the MKS V2.0 module's own silkscreen.
  - Shunt 2-3 (FALLBACK): module pin 4, via the module's own R8 resistor.
  - NEVER shunt both sides at once.
Both PDN legs route through a 220Ω GPIO protection resistor
(R_gpPDN_T1/T2) before reaching the jumper.

MS1/MS2 pull-up caution: the external 10kΩ pull-up fights the TMC2209's
own internal pull-down. Bench-verify the resulting high level against VIH
(~2.31V) before trusting an address bit — see brief §7.2.

----------------------------------------------------------------
8. LOAD CELLS — 2x HX711, shared clock (added v3.2)
----------------------------------------------------------------

Module          GND   DT (DOUT)          SCK (PD_SCK)   VCC
--------------  ----  -----------------  -------------  -----
HX711 #1 (SK4)  GND   GPIO42             GPIO37 (shared) 3.3V
HX711 #2 (SK5)  GND   GPIO21             GPIO37 (shared) 3.3V

VCC is 3.3V — do NOT power from 5V (DT would also read 5V and damage the
ESP32 GPIO). RATE jumper on each XFW-HX711 module set to 80Hz (not 10Hz).
SCK is shared between both modules; DT is separate per module — needs a
custom bit-bang driver (standard single-clock HX711 libraries don't apply).
Load-cell side wired to each module's own E+/E-/A+/A- screw terminal
(channel A, gain 128); channel B (fixed gain 32) left spare on the module.

----------------------------------------------------------------
9. TURBIDITY SENSING — I2C, shared bus (added v3.2)
----------------------------------------------------------------

Device     Addr   Mode                          Notes
---------  -----  ----------------------------  --------------------------
APDS9960   0x39   ALS, clear-channel, transmission  External LED hardwired ON via J16 (3.3V → 330Ω → LED+)
MAX30102   0x57   Backscatter, own onboard LEDs      18-bit ADC, hardware ambient cancellation

Bus: GPIO3 (SDA) / GPIO43 (SCL), 400kHz, one 4.7kΩ pull-up pair near U1.
Both modules connect via J15 (3.3V/GND/SDA/SCL). No address conflict.
Bring-up: I2C scanner should show both 0x39 and 0x57.

----------------------------------------------------------------
10. POWER RAILS
----------------------------------------------------------------

Rail   Source          Voltage    Max current  Key consumers
-----  --------------  ---------  -----------  ----------------------------
24V    PSU → F1 → F2   12–24V     6A peak      2× TMC2209 VM
5V     LM2596 buck     5V ±2%     2A           LED panel, TMC2209 VCC_IO, buzzer
3.3V   AMS1117-3.3     3.3V ±1%   800mA        ESP32, AD9833, op-amps, TFT logic, HX711 x2, I2C sensors

HX711 modules run from the 3.3V rail so DT/PD_SCK logic is directly
ESP32-compatible — do not power them from 5V (see Section 8).

================================================================

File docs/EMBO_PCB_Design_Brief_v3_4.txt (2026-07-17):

EMBO
Embolization Particle Sizing System
Custom MCU Board — PCB Design Brief

Field             |  Detail                                                                                                                  
---------------------------------------------------------------------------------------------------------------------------------------------
Document version  |  v3.4 — Full reference-designator naming pass; on-board backstop fuse; UAS/TMC/ESP32/USB hardening; GPIO short-fault protection added
Date              |  July 2026                                                                                                               
Status            |  For schematic re-design (rebuild from scratch) — 8 wiring blocks per team request                                        
MCU module        |  ESP32-S3-WROOM-1-N4 (4MB flash, PCB antenna, no PSRAM) — unchanged since v3.3                                              
Motor drivers     |  2× MKS TMC2209 V2.0 plug-in modules, socketed — current ceiling documented at 1.77A RMS (110mΩ sense), not 2.0A             
UI system         |  Breakout board via 20-pin IDC ribbon, pinout UNCHANGED — touch via GPIO repoint, one button — unchanged since v3.3           
Reverse polarity  |  AO4407A SOIC-8 P-MOSFET + BZX84C15 15V Zener gate clamp — pin numbering/orientation corrected v3.2 — power LED wiring added v3.4
Turbidity sensing |  APDS9960 (I2C 0x39, ALS transmission) + MAX30102 (I2C 0x57, backscatter) — shared I2C bus, LED hardwired to 3.3V             
Force sensing     |  2× load cell + HX711 amplifier, socketed, hardware fallback for StallGuard SG_RESULT — unaffected by this version's changes 
Fuse              |  5×20mm slow-blow glass, 5A 250V (T5A) off-board PRIMARY, inline before J14 — NEW v3.4: on-board 8A SMD backstop, F2           
Signal generator  |  AD9833 plug-in breakout module (VCC/DGND/SDATA/SCLK/FSYNC/AGND/OUT)                                                         

v3.4 SUMMARY OF CHANGES — this revision is a hardware-hardening and naming-discipline pass, prompted directly by (a) a live TMC2209 hot-swap incident on the fabricated v2.51 board that sparked and left the ESP32 module overheating on every subsequent power-up, and (b) the recognition that this document's passives had never been given individual reference designators, which had already let one BOM gap (the Tx/Rx bias-divider resistors) go uncounted. (1) FULL REFERENCE-DESIGNATOR NAMING PASS: every passive on the board — resistors, capacitors, diodes, the inductor, both LEDs — now has an explicit, unique ref designator assigned at the point it's introduced, plus a master lookup table (§12.3) and a "which reel do I actually need" non-standard-value quick reference (§12.2), specifically so a stray label like "input ceramic" can never again refer to the wrong physical part. (2) ON-BOARD BACKSTOP FUSE, F2: a second, on-board 8A SMD slow-blow fuse (Littelfuse Nano2 452-series) added in series after Q1, sized deliberately ABOVE the primary inline T5A so it never coordinates against it in a normal fault — it exists only to catch the case where the inline holder is empty, bypassed, or mis-fitted. See §2.1. (3) TMC2209 UART PIN CORRECTION: physical inspection of the actual MKS V2.0 module silkscreen found pin 5 (not pin 4) is the direct PDN_UART node, with the module's own R8 separator sitting between pin 5 and pin 4 — the OPPOSITE of what every version through v3.3 documented (inherited from generic third-party SilentStepStick writeups, not this specific module). Jumper default flipped accordingly on both U5 and U6. See §7.3. (4) TMC2209 MS1/MS2 ADDRESS JUMPERS: both U5 and U6 gain 1×3+shunt jumpers on MS1 and MS2 (4 headers total), making the two modules fully interchangeable across UART addresses 0–3 instead of hardwired at fixed addresses. See §7.2. (5) GPIO SHORT-FAULT PROTECTION: following the hot-swap/spark incident, a 220Ω series resistor is now placed on every ESP32-to-TMC2209 control line (STEP, DIR, EN, PDN_UART, MS1, MS2 — ×2 modules = 12 resistors) at the socket boundary, limiting fault current into the GPIO's internal clamp structure if a module is ever seated off-axis or hot-swapped again. A procedural line is also added to §13: power off and allow VM bulk caps to discharge before inserting/removing any TMC2209 module. See §7.6 and the fabricated-board incident note in §7.1. (6) UAS TX/RX HARDENING: IC1's Tx gain resistor (RfO1_1, 390Ω) changes footprint from SMD to THT for field gain adjustment (fixed value retained — no trim potentiometer, to avoid accidental drift); the Rx chain gains an explicit interstage AC-coupling network between stage 1 and stage 2 (CouAC_C2 + RbiasO2_3/RbiasO2_4) to block op-amp offset accumulation ahead of the ×10.1 second stage. See §5.2 and §5.5. (7) COMPONENT PACKAGE/PROCUREMENT CHANGES: TMC2209 VM bulk caps change from 100µF/50V THT radial to 100µF/50V SMD radial, 8mm height, placed beside (not under) each module socket for physical clearance; screw terminal J14 changes from 3.5mm to 5.0mm pitch for higher current margin and heavier-gauge wire; boot/reset buttons change from SMD 6×6 tactile to THT 6mm tactile for rework durability — mechanical footprint to be verified against the actual part's drawing, not the KiCad footprint name alone. See §6.3, §9, §12. (8) 24V POWER LED WIRED: LED_pwr + new R_LEDpwr (10kΩ) now explicitly wired in §2, tapping the PROTECTED rail (Q1 Source) rather than raw input, so the indicator only lights when Q1 is actually passing current correctly. (9) LIVE HARDWARE STATUS CARRIED FORWARD (open, not resolved by this revision): the v2.51 fabricated board's original LM2596 buck fault (external buck module workaround in place, U2 never bench-verified standalone) and the TMC2209 hot-swap short (ESP32 module suspected damaged, diagnosis in progress) are both still open — see §13.

DATASHEET / REFERENCE INDEX — every technical claim in this document traces to one of these sources. Two of the highest-stakes claims (Q1 pinout/orientation, OPA2354 package) were independently re-verified against the primary datasheet during this revision, not just carried forward from the prior review.

Tag      |  Source                                     |  Link                                                                                          
--------------------------------------------------------------------------------------------------------------------------------------------------
ESP32    |  ESP32-S3-WROOM-1 datasheet                 |  https://www.espressif.com/sites/default/files/documentation/esp32-s3-wroom-1_wroom-1u_datasheet_en.pdf
ESP32c   |  ESP32-S3 series datasheet (strapping)      |  https://www.espressif.com/sites/default/files/documentation/esp32-s3_datasheet_en.pdf                
AO4407   |  AO4407A Rev 11.1 (AOS)                     |  https://www.aosmd.com/res/datasheets/AO4407A.pdf                                                     
LM2596   |  LM2596 Rev G (TI)                          |  https://www.ti.com/lit/ds/symlink/lm2596.pdf                                                         
AMS      |  AMS1117 (Advanced Monolithic Systems)      |  Vendor datasheet — confirm against your specific supplier                                            
AD9833   |  AD9833 Rev G (Analog Devices)               |  https://www.analog.com/media/en/technical-documentation/data-sheets/ad9833.pdf                       
OPA      |  OPA2354 SBOS233F (TI)                       |  https://www.ti.com/product/OPA2354                                                                   
TMC      |  TMC2209 Rev 1.09 (ADI/Trinamic)             |  https://www.analog.com/media/en/technical-documentation/data-sheets/tmc2209_datasheet_rev1.09.pdf     
TMCmod   |  SilentStepStick pinout (Watterott)          |  https://learn.watterott.com/silentstepstick/pinconfig/tmc2209/                                       
HX711    |  HX711 (Avia Semiconductor)                  |  https://cdn.sparkfun.com/datasheets/Sensors/ForceFlex/hx711_english.pdf                              
MAX      |  MAX30102 (ADI/Maxim)                        |  https://www.analog.com/media/en/technical-documentation/data-sheets/max30102.pdf                     
APDS     |  APDS-9960 (Broadcom AV02-4191EN)            |  Search "APDS-9960 datasheet Broadcom"                                                                 
SMBJ     |  SMBJ28A / SMB (DO-214AA) package            |  https://www.littelfuse.com/assetdocs/tvs-diodes-smbj-series-datasheet                                 
Nano2    |  Littelfuse 452-series Slo-Blo Nano2 (F2)     |  https://www.littelfuse.com/assetdocs/fuse-452-and-454-datasheet — confirm 125VDC vs 32VDC rating against this primary source, not aggregator listings
BAV99    |  BAV99 dual series diode pinout               |  Vendor datasheet (e.g. onsemi/Vishay) — confirm pin1/pin2/pin3 = anode1/cathode2/junction before wiring Drx1/Drx2
KiCad    |  KiCad 10 (10.0.4 stable, 2026)              |  https://www.kicad.org — footprint/symbol library nicknames unchanged from KiCad 9; v10 adds "Jumpers" for off-board module pads and PCB Design Blocks

======================================================================
REVISION HISTORY
======================================================================

Version  |  Summary of change                                                                                               
----------------------------------------------------------------------------------------------------------------------------
v2.0     |  STM32G474 → ESP32-S3-WROOM-1-N8. USB-C native programming. BLE debug.                                           
v2.1     |  UAS gain correction. TMC2209 VCP + SPREAD fixes. Power hardening.                                               
v2.2     |  AO3401A → AO4407A + Zener. Motor 4×2-pin → 2×6-pin. KiCad footprints.                                           
v2.3     |  ILI9341 confirmed, 14-pin header. RPi UART JST-XH 3-pin. C_adc explicit. USB-C pins documented.                 
v2.4     |  UI system moved to breakout board via 20-pin IDC ribbon.                                                        
v2.5     |  TMC2209 QFN-28 → BTT module sockets. SpreadCycle firmware-enforced. CLK pin correction.                         
v2.51    |  ERRATA: ESP32 module decoupling corrected (single 3V3 pin). AD9833 RSET/COMP/200Ω errors corrected (§2.2, §5.1).
v3.0     |  F1 → 5×20mm fuseholder + 5A slow-blow. R_snub → 0603. Added APDS9960+MAX30102 turbidity sensing (I2C). Motor conn. 6-pin→4-pin.
v3.1     |  AD9833 → plug-in module (MCLK fix). BTT→MKS TMC2209 V2.0. PDN_UART → 2-GPIO. Motor conn. XH→PH. LED hardwired. GPIO budget corrected.
v3.2     |  Full rebuild in 8 wiring blocks. Added HX711×2 load-cell fallback. Touch removed, GPIOs freed. Fuse off-board. Q1/OPA2354/SMBJ corrected.
v3.3     |  Module corrected N8→N4. Touch restored via GPIO repoint only (no breakout change). One button. BOM table formatting fixed. GPIO datasheet re-verified.
v3.4     |  Full ref-designator naming pass. F2 backstop fuse added. TMC UART pin4/5 corrected from module silkscreen. MS1/MS2 address jumpers. 12× GPIO protection resistors after hot-swap spark incident. Rf → THT. Rx interstage AC coupling. J14 → 5.0mm. Buttons → THT. VM bulk caps → SMD. Power LED wired.

====================================================================================
1. SYSTEM OVERVIEW, POWER RAILS, AND MASTER GPIO MAP
====================================================================================

1.1 Overview
------------
EMBO is a closed-loop embolic-agent preparation device. The MCU board integrates the
UAS acoustic chain, a CV-camera trigger, two stepper actuators (TMC2209), two limit
switches, an I2C turbidity pair (APDS9960 + MAX30102), a UI breakout via 20-pin IDC,
USB-C native programming, and — new in v3.2 — a 2-channel load-cell force sensor
(HX711 x2) at the syringe contact point as a StallGuard fallback.

MCU module: ESP32-S3-WROOM-1-N4 (4 MB flash, PCB antenna, NO PSRAM). [ESP32] CORRECTED v3.3 — prior versions of this brief documented N8 (8MB); the actual module on hand is N4 (4MB). Confirmed against the datasheet that this changes nothing pin-side (see §1.3.1) — flash capacity only affects OTA partition sizing in firmware, not GPIO behavior.
A no-PSRAM variant (N4, N8, or N16 — any plain suffix without R or V) is REQUIRED, because GPIO35/36/37 are only free for the SPI
bus on non-PSRAM parts — on R8 (Octal PSRAM) variants IO35/36/37 are consumed internally
and must not be used. [ESP32, "IO35, IO36, IO37 connect to Octal SPI PSRAM and are not
available for other uses"]

1.2 Power rails
---------------
Rail    | Source            | Voltage   | Consumers                                        | Max
--------------------------------------------------------------------------------------------------
24 V    | PSU (via inline   | 12-24 V   | 2x TMC2209 module VM                              | 6 A pk
        | fuse + Q1)        |           |                                                  |
5 V     | LM2596-5.0 buck   | 5 V ±2%   | LED panel, TMC2209 VCC_IO, buzzer                | 2 A
3.3 V   | AMS1117-3.3 LDO   | 3.3 V ±1% | ESP32, AD9833 module, OPA2354 x2, TFT logic,     | 800 mA
        |                   |           | HX711 x2, I2C sensors' bus                        |

NOTE: HX711 modules run from the 3.3 V rail (see Block 9) so their DOUT/PD_SCK logic
is 3.3 V — directly ESP32-compatible with no level shifting. Do NOT power them from 5 V.

1.3 Master GPIO map (35 of 36 used; GPIO45 free, broken out to SP7)
-------------------------------------------------------------------------
GPIO | Signal        | Dir    | Connects to               | Notes
------------------------------------------------------------------------------------------------------
0    | BOOT          | strap  | R_BOOT/C_BOOT/SW_boot     | Strapping (boot mode). [ESP32c]
1    | UAS_ADC       | AIN    | Envelope out              | ADC1_CH0 (ADC1 avoids Wi-Fi/ADC2 clash). C_adc <2 mm.
2    | STATUS_LED    | OUT    | R_statLED(330R) → LED_stat → GND | 
3    | I2C_SDA       | BIDIR  | J15 p3 (sensors)          | Strapping (JTAG src), no internal pull; 4.7k to 3V3. See 5.6.
4    | TMC_UART_TX   | OUT    | R_UART(1k) → R_gpPDN_T1/T2 → PDN bus (pin 5) | TX leg of TMC UART pair. Block 6. PDN target pin corrected v3.4 — see §7.3.
5    | STEP_M1       | OUT    | R_gpSTEP_T1 → U5 STEP     | MCPWM/LEDC. 220R GPIO protection added v3.4, §7.6.
6    | DIR_M1        | OUT    | R_gpDIR_T1 → U5 DIR       | 220R GPIO protection added v3.4, §7.6.
7    | EN_M1         | OUT    | R_gpEN_T1 → U5 EN         | 10k pull-up on main board. 220R GPIO protection added v3.4, §7.6.
8    | STEP_M2       | OUT    | R_gpSTEP_T2 → U6 STEP     | MCPWM/LEDC. 220R GPIO protection added v3.4, §7.6.
9    | DIR_M2        | OUT    | R_gpDIR_T2 → U6 DIR       | 220R GPIO protection added v3.4, §7.6.
10   | EN_M2         | OUT    | R_gpEN_T2 → U6 EN         | 10k pull-up on main board. 220R GPIO protection added v3.4, §7.6.
11   | BTN1          | IN     | IDC 16                    | Breakout pull-up + debounce.
12   | T_CS          | OUT    | IDC 11                    | CHANGED v3.3 (was BTN2). Touch chip select, restored — see §8.3.
13   | BUZ_PWM       | OUT    | IDC 18                    | LEDC PWM.
14   | LIMIT_M1      | IN     | J6                        | 100 nF debounce.
15   | LIMIT_M2      | IN     | J7                        | 100 nF debounce.
16   | EC11_A        | IN     | IDC 13                    | Breakout pull-up + debounce.
17   | EC11_B        | IN     | IDC 14                    | Breakout pull-up + debounce.
18   | EC11_SW       | IN     | IDC 15                    | Breakout pull-up + debounce.
19   | USB D-        | USB    | J13 A7+B7                 | Native USB PHY. [ESP32]
20   | USB D+        | USB    | J13 A6+B6                 | Native USB PHY. [ESP32]
21   | HX711_2_DT    | IN     | HX711 #2 DOUT             | Unaffected by touch restoration — HX711 is on its own header, not the ribbon. See §10.2.
35   | SPI_MOSI      | OUT    | AD9833 SDATA + IDC 5      | SPI2 (FSPI). PSRAM-free variant only (N4 here). [ESP32]
36   | SPI_CLK       | OUT    | AD9833 SCLK + IDC 7       | SPI2, 20 MHz, shared TFT + touch. PSRAM-free variant only (N4 here). [ESP32]
37   | HX711_SCK     | OUT    | both HX711 PD_SCK (shared)| Unaffected by touch restoration. See §8.3, §10.2.
38   | AD9833_CS     | OUT    | AD9833 FSYNC              |
39   | TFT_CS        | OUT    | IDC 8                     | (ESP32-S3 JTAG MTCK; fine, JTAG over USB.)
40   | TFT_DC        | OUT    | IDC 9                     | (MTDO.)
41   | TFT_RST       | OUT    | IDC 10                    | (MTDI.)
42   | HX711_1_DT    | IN     | HX711 #1 DOUT             | Unaffected by touch restoration. See §8.3, §10.2.
43   | I2C_SCL       | OUT    | J15 p4 (sensors)          | UART0-TX by default but board uses USB-JTAG; 4.7k to 3V3.
44   | TMC_UART_RX   | IN     | R_UART → R_gpPDN_T1/T2 → PDN bus (pin 5) | RX leg of TMC UART pair. PDN target pin corrected v3.4 — see §7.3.
46   | T_DO          | IN     | IDC 6                     | CHANGED v3.3 (was FREE/strap). Touch data out, restored — placed here deliberately, see §8.3 for why this is the safe strapping-pin choice.
47   | RPi_TX        | OUT    | J3 p3                     | UART1 TX 921600.
48   | RPi_RX        | IN     | J3 p2                     | UART1 RX.
45   | FREE (strap)  | -      | SP7 1-pin header          | VDD_SPI select; MUST be low at boot. Sole remaining spare pin on the board — see §8.3 for why T_IRQ was deliberately not placed here.

IDC pins now NC on the main board (breakout unchanged): pin 12 (T_IRQ, polled instead — see §8.3) and pin 17 (BTN2, removed — see §8.1). See §8 for the full IDC pinout.

1.3.1 N4 vs N8 — confirmed no pinout impact
------------------------------------------------
This board uses ESP32-S3-WROOM-1-N4 (corrected from N8 in earlier versions — see revision history). Checked directly against the module comparison table in the WROOM-1 datasheet [ESP32]: N4 and N8 share the identical die (plain ESP32-S3, no PSRAM either way) — the only difference is external flash chip capacity. Every GPIO-side fact in this document (GPIO35/36/37 free since there's no PSRAM, GPIO45/46 strapping behavior, GPIO47/48 running at 3.3V since this isn't a "V"-suffix module) applies identically to N4 and N8. Flash capacity only affects firmware OTA partition sizing, not any hardware pin assignment in this brief.

====================================================================================
2. INPUT PROTECTION (BLOCK 1)
====================================================================================
Order of elements (source to board):
   PSU(+) → [INLINE 5x20 mm fuse, F1] → J14 screw terminal → F2 (on-board SMD backstop) →
   Q1 (reverse polarity) → D5 TVS across 24 V rail → R_LEDpwr/LED_pwr indicator →
   24 V rail (buck + motor VM bulk).

2.1 Inline fuse F1 (OFF-BOARD, PRIMARY) + on-board backstop F2 (NEW v3.4)
--------------------------------------------------------------------------
F1 (primary, off-board):
- 5x20 mm cartridge, 5 A 250 V SLOW-BLOW (time-delay, "T5A"), glass.
- Inline panel/wire holder in the +24 V lead before J14. Not a PCB part.
- Slow-blow: correct for inductive/motor inrush (a fast-blow nuisance-trips on stepper
  startup). Glass: visible blown indication, field-replaceable by hand.
- SIZING CHECK (do this): F1 carries ALL board current, not just motors. Confirm the true
  steady-state 24 V input draw. For 2x sub-1.8 A-RMS steppers the VM SUPPLY current is far
  below the coil current (the driver is a chopper: supply A ~= coil W / 24 V / eff.),
  typically ~1 A steady with the "6.5 A peak" being acceleration inrush. Keep continuous
  load <= ~75 % of the fuse rating; if real continuous draw approaches 4.5-5 A, step up to
  T6.3A. The inline holder makes this a 10-second field change — start conservative.
JUST IN CASE: keep T3.15A / T5A / T6.3A on the bench during bring-up.

F2 (NEW v3.4, on-board backstop, NOT the primary protection):
- Littelfuse Nano2 452-series Slo-Blo, 8 A, 125 VAC/VDC, 2410 (6125 metric) SMD, part
  0452008.MRL or equivalent. Placed on-board between J14 and Q1's Drain.
- DELIBERATELY sized ABOVE F1 (8 A vs F1's 5 A) so the two elements do not coordinate
  against each other in a normal motor-stall fault — F1 (lower rating, field-replaceable)
  is meant to open first every time. F2 exists only to catch the case where F1's holder is
  empty, bypassed, or mis-fitted with an oversized fuse; it is not a substitute for F1.
- Silkscreen clearly: "F2 BACKSTOP 8A — PRIMARY IS INLINE T5A" so nobody mistakes it for
  the primary protection during bring-up or field service.
- CAVEAT: distributor listings disagree on whether this Nano2 452 series is rated 125VDC
  or only 32VDC continuous — confirm against the primary Littelfuse 452/454 datasheet
  before final BOM lock, not against aggregator listings alone.

2.2 Reverse-polarity P-MOSFET — Q1 (AO4407A) + Dprot (BZX84C15)  [AO4407]
---------------------------------------------------------------------
Component | Value / part                    | Connection
-----------------------------------------------------------------------------------------------
Q1        | AO4407A, P-ch, VDS -30 V,        | Drain (pins 5-8) → F2 → J14 V+ (INPUT side).
          | VGS(max) +/-25 V, ID -12 A,      | Source (pins 1-3) → 24 V rail (LOAD side).
          | RDS(on) 13 mΩ @ -10 V, SOIC-8    | Gate (pin 4) → R_gate / Dprot junction.
R_gate    | 10 kΩ 0402                       | Gate → GND.
Dprot     | BZX84C15, 15 V Zener, SOT-23     | Cathode → Source. Anode → Gate. Clamps VGS to -15 V. (was "D7")

PINOUT (from [AO4407] p.1): Source = pins 1,2,3 ; Gate = pin 4 ; Drain = pins 5,6,7,8.
  *** This corrects the v3.1 text, which listed Gate=1 / Source=2-4. Verify the KiCad
      symbol's pin→function mapping before routing; DO NOT trust pin numbers from prose. ***

ORIENTATION (corrected v3.2): For a P-channel high-side reverse-polarity switch the body
diode (anode=Drain, cathode=Source) must be REVERSE-biased during a reverse fault so it
blocks. That requires Drain → input, Source → load (as above). v3.1 had Source→input /
Drain→load, which lets the body diode conduct a reverse fault and defeats the protection.
BENCH CHECK: power Q1 from a current-limited supply and deliberately reverse the leads — a
correct board draws ~0 mA reversed.

VGS CLAMP: at normal polarity Source sits at +24 V and Gate is pulled to GND via R_gate,
so unclamped VGS = -24 V, which exceeds a conservative rating. BZX84C15 clamps VGS to
-15 V, safely inside the AO4407A +/-25 V VGS(max) [AO4407 p.1]. The Zener also fails "off"
(gate to source), so a fault here does not release smoke.

2.3 TVS — Dclamp (SMBJ28A)
---------------------------
- SMBJ28A, unidirectional, 28 V standoff, ~45.4 V max clamp, 600 W, SMB (DO-214AA).
  *** FOOTPRINT CORRECTION: SMBJ = SMB (DO-214AA), not SMA. v3.1 listed D_SMA, which is
      the SMAJ (400 W) package. Use Diode_SMD:D_SMB for SMBJ28A, OR switch the part to
      SMAJ28A (400 W) if you keep D_SMA. Do not pair SMBJ with an SMA land. ***
- Placement: across the 24 V rail AFTER Q1 (protects the rail; reverse faults are handled
  by Q1, so the TVS never sees reverse voltage).
- MARGIN NOTE: SMBJ28A clamps at ~45 V, above the TMC2209 VM abs-max (~29-30 V, [TMC]).
  The 24 V-rail / 29 V-max window is inherently tight. If you run 24 V, confirm the PSU
  cannot overshoot/load-dump beyond ~29 V and rely on module VM bulk caps for fast
  transients. If you run 12 V, this is a non-issue (large margin).

2.4 24V power LED (NEW v3.4 — wiring closed out; parts already existed in v3.3 BOM unwired)
---------------------------------------------------------------------------------------------
LED_pwr (red 0805) + R_LEDpwr (10 kΩ 0402, NEW ref) placed AFTER Q1, tapping the PROTECTED
rail (Q1 Source — the same node D5/buck/VM bulk all tap from), not the raw input side.
Rationale: an indicator wired to raw input lights on any polarity and stays lit even if Q1
fails open, telling you nothing useful; wired to the protected rail it only lights when Q1
is actually passing current the right way — same "tells you the truth" philosophy as D7
failing safe. I = (24V - Vf~2V) / 10kΩ ≈ 2.2 mA, P ≈ 48 mW — well inside an 0805 resistor's
typical 1/8 W rating. No new non-standard value: 10kΩ is already the board's common reel.
Placement: anywhere convenient on the protected-rail side; does NOT need to be inside the
tight Q1/D7 3mm keepout (low-current DC load, no EMI/loading concern at 2.2 mA).

(Section renumbering note: all "D5" references above and below now read "Dclamp"; all "D7" now read "Dprot" — see §12.3 Master Reference-Designator Table for the full old→new cross-reference.)

WIRING GUIDE (Block 1): J14 pin1 = V+, pin2 = GND. V+ → F2 → Q1 Drain (pins 5-8). Q1 Source
(1-3) = protected 24 V rail. Q1 Gate (4) node ties R_gate (to GND) and Dprot anode; Dprot
cathode to Q1 Source. Dclamp anode to GND, cathode to 24 V rail. Protected rail → R_LEDpwr
→ LED_pwr anode; LED_pwr cathode → GND. Keep Q1/Dprot within 3 mm; wide copper on the 24 V
rail; TVS ground return short and direct.

====================================================================================
3. BUCK CONVERTER — 24V → 5V, LM2596-5.0 (BLOCK 2)
====================================================================================
Pin functions [LM2596 Rev G, Table 6-1]: 1 = +VIN, 2 = OUTPUT (internal switch / SW node),
3 = GROUND, 4 = FEEDBACK, 5 = ON/OFF.

Parameter        | Requirement
------------------------------------------------------------------------------------------
IC (U2)          | LM2596S-5.0 fixed 5 V, TO-263-5. Vin 8-40 V, 150 kHz, 3 A.
Input electrolytic| C_inBU_E1 — 100 µF 50 V radial, low-ESR, close to pin 1.
Input ceramic    | C_inBU_C1 — 100 nF, bypass at pin 1.
Catch diode      | Dcatch — SS34A (3 A, 40 V Schottky, SMA). CATHODE → pin 2 (SW node); ANODE → GND.
                 |   *** This is the exact v2.51 failure (symbol pin swap). Verify polarity. ***
Inductor         | Lbuck — 100 µH, >=3 A saturation, shielded. From pin 2 to output node.
Output electrolytic| CouBU_E1 — 220 µF 16 V low-ESR radial.
Output ceramic   | C_ouBU_C1 — 100 nF, bypass at output node.
Snubber resistor | Rsnub — 10 Ω 0603, across the SW node (pin 2 to GND).
Snubber ceramic  | Csnub — 1 nF 50 V, between Rsnub and GND.
Bleed            | Rbleed — 4.7 kΩ from 5 V to GND.

SNUBBER THERMAL (verified): P = C.V^2.f/2 = 1 nF x 24^2 x 150 kHz / 2 ≈ 43 mW = 68 % of an
0402's ~63 mW rating → 0603 (~100 mW) is correct. It is the only 0603 resistor on the board.
CATCH-DIODE RATING: SS34A 3 A / 40 V is adequate for the 2 A load at 24 V input; 40 V leaves
little margin if input ever nears the 40 V device max — fine at your real 12-24 V.

WIRING GUIDE (Block 2): 24 V rail → LM2596 pin1 (+ C_inBU_E1 + C_inBU_C1 to GND). Pin 3 →
GND. Pin 5 (ON/OFF) → GND to enable (or to a control GPIO if soft-enable ever wanted —
currently GND). Pin 2 → Lbuck → 5 V node (+ CouBU_E1 + C_ouBU_C1 to GND, + Rbleed). Dcatch
cathode to pin 2, anode to GND, placed within 5 mm of pin 2. Rsnub+Csnub across pin 2/GND.
Feedback pin 4 → 5 V node (fixed version senses internally; tie per LM2596-5.0 fixed-output
app circuit). Keep the SW-node copper compact; single-point ground the power return.

====================================================================================
4. LDO — 5V → 3.3V, AMS1117-3.3 (BLOCK 3)
====================================================================================
Parameter   | Requirement
--------------------------------------------------------------------------------------------
IC (U3)     | AMS1117-3.3, SOT-223-3. Vout 3.3 V, up to 1 A (800 mA budget). Dropout ~1.3 V.
Input tantalum | CinLD_T1 — 10 µF 16 V tantalum, Case A (16 V for real derating margin on a 5 V input).
Output tantalum| CouLD_T1 — 10 µF 10 V tantalum, Case A (3x derating at 10 V — fine).
Output ceramic | CouLD_C1 — 100 nF bypass.
Thermal     | SOT-223 tab (= Vout) → >=100 mm^2 copper + >=4 thermal vias.

THERMAL (corrected math): worst-case dissipation P = (5 - 3.3) x 0.8 = 1.36 W at the full
800 mA budget (v3.1's "~850 mW" was the 500 mA figure). 1.36 W on SOT-223 is hot; keep the
copper pour + vias, and confirm typical continuous 3.3 V load is well under 800 mA (ESP32
Wi-Fi TX bursts are the peak driver). Dropout is OK: ~1.3 V vs 1.7 V headroom.
JUST IN CASE: lay out the SOT-223 so a pin-compatible higher-current / lower-dropout LDO
drops in, and leave board room for a small 3.3 V buck if the linear runs too hot in-enclosure.

WIRING GUIDE (Block 3): 5 V → pin 3 (Vin) + CinLD_T1 to GND. Pin 1 → GND. Pin 2 / tab →
3.3 V + CouLD_T1 + CouLD_C1 to GND. Fan the 3.3 V pour under the tab with the vias.

====================================================================================
5. UAS SIGNAL CHAIN (BLOCK 4)
====================================================================================
1 MHz acoustic chain on the 3.3 V rail; AD9833 sweepable 0.5-3 MHz in firmware.

5.1 AD9833 signal generator — plug-in module (SK3)  [AD9833]
-----------------------------------------------------------
Module pins (7): VCC / DGND / SDATA / SCLK / FSYNC / AGND / OUT.
Module pin | Connects to                | Notes
-------------------------------------------------------------------------------------------
VCC        | 3.3 V                      | Chip is 2.3-5.5 V; confirm the module has no 5 V-only reg.
DGND       | GND                        |
AGND       | GND (single star point)    | Tie DGND+AGND to one star-ground, not nearest trace.
SDATA      | GPIO35 (SPI2 MOSI)         |
SCLK       | GPIO36 (SPI2 CLK)          |
FSYNC      | GPIO38 (AD9833_CS)         |
OUT        | CpreAC_C1 (100 nF) AC-couple → IC1 chA non-inv input | No intermediate resistor.

AD9833 module decoupling: CdecAD_C8 (10 µF ≥16V X5R 0805) + CdecAD_C1 (100 nF), at SK3's VCC pin.

KEY FACTS [AD9833 Rev G, p.7]: (a) 200 Ω load resistor is ON-CHIP — no external R_load.
(b) There is NO RSET pin (that belongs to the AD9834) — no R_RSET. (c) The chip has NO
internal oscillator: it needs MCLK. The module carries its own 25 MHz oscillator wired to
MCLK internally, which is the whole point of using the module. (d) Output ≈ 0.6 Vpp typ.
(e) SPI Mode 2 (CPOL=1; data clocked on the FALLING SCLK edge).
BRING-UP: scope OUT with only VCC/GND (no SPI, no firmware) to confirm the onboard clock is
alive — SPI writes completing only proves the digital interface, not that MCLK/output work.

5.2 Tx amplifier — IC1 ch-A, G = 4.9  [OPA]
-------------------------------------------
IC (IC1)   | OPA2354, ch-A. 250 MHz unity-gain BW / 100 MHz GBW, 2.5-5.5 V, RRIO.
Bias       | RbiasO1_1 + RbiasO1_2, 10 kΩ each (3.3 V → non-inv → GND) = 1.65 V mid-rail.
Input      | CpreAC_C1 (100 nF) AC couple from AD9833 OUT (~0.6 Vpp).
Gain       | RfO1_1 = 390 Ω 1%, RgO1_1 = 100 Ω 1%; G = 1 + Rf/Rg = 4.9.
Output     | R_TL1 (47 Ω series) + CinAC_C1 (100 nF couple) → J1 SMA.
Decoupling | CdecO1_C1 (100 nF) within 2 mm of V+ + CdecO1_C8 (10 µF 0805) bulk.
CLIP MARGIN (verify on scope): at the datasheet-typical 0.6 Vpp input, G=4.9 → ~2.94 Vpp,
which fits the 3.3 V rail (RRIO swings within 100 mV of rails) but with little margin; a hot
part near 0.65 Vpp → ~3.19 Vpp clips. Be ready to trim RfO1_1 down. Bandwidth at G=4.9 is
~20 MHz (100 MHz GBW) >> 3 MHz — ample.
RfO1_1 FOOTPRINT — CHANGED v3.4, SMD → THT: switched to a through-hole 1% resistor
specifically so gain can be hand-swapped in the field without hot-air rework. Electrically
fine at 1 MHz — lead inductance/capacitance (~10-20nH, ~0.5-1pF) puts any added pole near
175 MHz on a 100 MHz-GBW part, nowhere near the 1 MHz operating frequency. DELIBERATELY NOT
a trim potentiometer — a fixed swappable THT part was chosen over a trimpot to avoid
accidental gain drift from an unintentional wiper knock. Value unchanged at 390 Ω; the real
gate on any future value change is still an unmeasured AD9833 real output amplitude — scope
SK3's OUT pin (VCC/GND only, no SPI) before trusting any gain number in this section.

5.3 IC1 ch-B — unused, tied off
-------------------------------
Non-inv (pin 5) → 1.65 V mid-rail. Inv (pin 6) → output (pin 7): unity follower. (No NC
pins on the OPA2354; all 8 used.)

5.4 Rx input protection
-----------------------
R_in (100 Ω 0402, series fault limiter) → Drx1 (BAV99, clamp 0-3.3 V) → IC2.
Drx1 WIRING (BAV99 is a series-pinout dual diode, NOT common-anode/common-cathode — only
the package's internal junction pin can carry the signal): common junction pin → signal
node; the anode-only pin → GND; the cathode-only pin → 3.3 V. Confirm this against the
actual BAV99 pinout diagram before placing — do not wire "both cathodes to 3.3V", which is
not physically achievable with this pinout and would leave one clamp direction unprotected.

5.5 Rx two-stage amplification — G = 100 total  [OPA]
-----------------------------------------------------
Stage 1 | IC2 ch-A | RfO2_1 910 Ω 1% | RgO2_1 100 Ω 1% | 10.1x
Interstage AC coupling (NEW v3.4) | CouAC_C2 (100 nF) + RbiasO2_3/RbiasO2_4 (10 kΩ each,
1.65V mid-rail) between IC2 chA's output and chB's non-inv input — blocks op-amp offset
accumulation ahead of the ×10.1 second stage. High-pass corner ≈1/(2π×5kΩ×100nF)≈320 Hz,
far below the 1 MHz operating frequency — no passband impact.
Stage 2 | IC2 ch-B | RfO2_2 910 Ω 1% | RgO2_2 100 Ω 1% | 10.1x  (total ~100x; max non-clip Rx in ~32 mVpp)
Per-stage bandwidth ~10 MHz (100 MHz GBW / 10.1) >> 1 MHz — ample.
Rx input bias (chA, at CouAC_C1): RbiasO2_1 + RbiasO2_2, 10 kΩ each, 1.65V mid-rail.
IC2 decoupling: CdecO2_C1 (100 nF) + CdecO2_C8 (10 µF 0805) bulk.

5.6 Envelope detector + ADC — GPIO1
-----------------------------------
Denv (BAT54, Vf~0.3 V envelope rectifier, anode toward signal flow) → R_envRC1 (10 kΩ) +
C_envRC1 (10 nF, t=100µs, fc≈1.6 kHz, 5t settling ≈ 500µs) → Drx2 (BAV99, hard clamp at
GPIO1, same wiring caution as Drx1 above) → C_adc (100 nF, GPIO1 to AGND, within 2 mm of
the GPIO1 pad, separate from C_envRC1). GPIO1 = ADC1_CH0.

5.7 OPA2354 PACKAGE / FOOTPRINT (corrected v3.2)  [OPA]
------------------------------------------------------
The dual OPA2354 is NOT offered in plain SOIC-8. Choose ONE and match the footprint:
  - OPA2354AIDDA  → SO PowerPAD-8 (DDA), 1.27 mm pitch, exposed thermal pad.
        Footprint: Package_SO:SOIC-8-1EP_3.9x4.9mm_P1.27mm_EP2.29x3mm (tie EP to GND).
        RECOMMENDED for hand assembly (1.27 mm pitch).
  - OPA2354AIDGKR → VSSOP-8 (DGK), 0.65 mm pitch.
        Footprint: Package_SO:VSSOP-8_3.0x3.0mm_P0.65mm.
Do NOT use Package_SO:SOIC-8_3.9x4.9mm_P1.27mm for IC1/IC2 (that plain-SOIC land is correct
only for Q1, which genuinely is SOIC-8).

WIRING GUIDE (Block 4): keep IC1 and IC2 >=15 mm apart; UAS analog on the top layer only,
no vias in UAS paths. SK3 placed for a short, direct OUT→coupling-cap→IC1 run. Star-ground
the AD9833 grounds. C_adc hugs the GPIO1 pad.

====================================================================================
6. ESP32-S3-WROOM-1-N4 — U1 (BLOCK 5)
====================================================================================
6.1 Footprint / keepout
-----------------------
18.0 x 25.5 x 3.1 mm, castellated 1.27 mm pitch, 41 pads.
Footprint: RF_Module:ESP32-S3-WROOM-1.
ANTENNA KEEPOUT: no copper/traces/vias/parts within 15 mm of the PCB antenna, ALL layers.
EPAD: solder to GND pour (improves thermal; not strictly required).

6.2 Power decoupling
--------------------
The module exposes ONE external 3.3 V pin (castellated pin 2, "3V3"). VDD3P3 / VDD3P3_RTC /
VDD3P3_CPU are internal die rails. Decouple the single 3V3 pad with CdecES_C8 (10 µF X5R
0805) + CdecES_C1 (100 nF X7R 0402) within 2 mm. (Do not add the old three-group decoupling.)

6.3 EN reset + boot — buttons CHANGED v3.4: SMD 6×6 → THT 6mm tactile
------------------------------------------------------------------------
R_EN (10 kΩ, 3V3→EN); C_EN (1 µF, EN→GND); SW_reset (EN→GND).
R_BOOT (10 kΩ, 3V3→GPIO0); C_BOOT (100 nF, GPIO0→GND); SW_boot (GPIO0→GND).
The 10 kΩ / 1 µF EN RC is exactly Espressif's recommended value [ESP32, Peripheral Schematics].
BUTTON FOOTPRINT CHANGE (v3.4): SW_reset and SW_boot move from SMD 6x6 tactile (prone to
pad lift under repeated hard presses on a bring-up board) to THT 6mm tactile for rework
durability. TWO THINGS TO VERIFY BEFORE ROUTING, not assumed from the "6mm" name: (1) "6mm
THT tactile" is not necessarily 6mm PITCH — common 4-pin THT parts are often ~6.5mm on one
axis and ~4.5mm on the other; compare the actual part's mechanical drawing against whatever
KiCad footprint gets selected, don't trust the footprint name alone. (2) the four pins are
two internally-shorted PAIRS, not four independent nodes — wire diagonally opposite pins;
picking the wrong pair permanently shorts EN (or GPIO0) to GND and the board looks exactly
like a dead ESP32 at first power-up.

6.4 USB-C programming (J13)
---------------------------
D- (A7+B7 tied) → GPIO19. D+ (A6+B6 tied) → GPIO20. [ESP32 native USB]
CC1 (A5) R_cc1 5.1 kΩ to GND; CC2 (B5) R_cc2 5.1 kΩ to GND (mandatory sink/UFP Rd). VBUS →
5 V via Dusb (1N5819). SBU1/SBU2/SSTX/SSRX = NC. CC resistors within 5 mm of J13.

6.5 Strapping pins
------------------
Four strapping pins: GPIO0 (boot), GPIO3 (JTAG source), GPIO45 (VDD_SPI voltage), GPIO46 (boot mode) [ESP32c]. Rules:

GPIO45 must read LOW at boot — its internal weak pull-down gives VDD_SPI = 3.3V, correct for a PSRAM-free module (N4 here). Never drive it high at reset. As of v3.3 this is the board's sole remaining spare GPIO — broken out to SP7, left unpopulated, no signal assigned. See §8.3 for why touch's IRQ line was deliberately kept off this pin rather than placed here.

GPIO46 must not read HIGH at the same moment GPIO0 reads LOW (that specific combination is invalid and triggers unexpected behavior; GPIO0 only goes low during a deliberate firmware-flash entry, not normal boot). CHANGED v3.3: GPIO46 is now T_DO (touch data out) — an ESP32-S3 *input*, driven by the touch chip only when its own CS is asserted and left high-impedance otherwise. With no external pull-up on this specific signal (see §8.3), it settles to the chip's internal weak pull-down by default and does not fight the strap read under normal conditions. Confirm on the assembled board that no accidental pull-up was added on this net before relying on this.

GPIO3 (I2C_SDA) has no internal pull; the 4.7kΩ I2C pull-up holds it high at reset. This is benign when debugging over USB-Serial/JTAG (which this board does), but confirm it does not select an unwanted JTAG source at boot.

6.6 I2C notes
-------------
SDA=GPIO3, SCL=GPIO43, 400kHz (both sensors). One pair of 4.7kΩ pull-ups to 3.3V, near U1 (shared bus, not per device). GPIO43 is UART0-TX by default in Arduino-ESP32 but the board uses USB-Serial/JTAG for all debug, so GPIO43 is free — call Serial0.end() or don't remap.

6.7 GPIO capability verification — every assignment checked against the datasheet
---------------------------------------------------------------------------------------
Requested for v3.3: a systematic re-check that every signal assigned to a pin in this document is something that pin can actually do, not just a number that happened to be free. Checked directly against the ESP32-S3-WROOM-1 and ESP32-S3 series datasheets [ESP32, ESP32c], not carried forward from memory.

Analog input (UAS_ADC, GPIO1): must be an ADC1 channel, not ADC2 — ADC2 shares hardware with the Wi-Fi radio and becomes unreliable whenever Wi-Fi is active. GPIO1 is ADC1_CH0. Confirmed correct.

Fixed-function pins (USB D+/D-, GPIO19/20): these are the native USB PHY pins and cannot be reassigned to any other function on this module — confirmed they carry no other signal anywhere in this design.

PSRAM-gated pins (GPIO35/36/37): only free for general use on a module with no PSRAM in the package. Confirmed this board's ESP32-S3-WROOM-1-N4 has no PSRAM (§1.3.1) — all three pins are legitimately available and are used for SPI_MOSI, SPI_CLK, and HX711_SCK respectively.

Voltage-gated pins (GPIO47/48): run at 1.8V instead of 3.3V only on "V"-suffix modules (VDD_SPI = 1.8V). This module has no V suffix, so both run at normal 3.3V logic — confirmed safe for RPi_TX/RPi_RX as assigned.

Strapping pins (GPIO0, 3, 45, 46): each individually addressed in §6.5. GPIO46 additionally confirmed output-*and*-input capable post-boot (not input-only, an earlier open question in this project now resolved against the datasheet) — relevant because T_DO only needs it as an input, but confirms the pin isn't more restricted than assumed.

JTAG-shared pins (GPIO39/40/41, used for TFT_CS/DC/RST): these double as MTCK/MTDO/MTDI. Since this board uses USB-Serial/JTAG rather than the dedicated JTAG pins for debugging, no conflict — confirmed no other part of this design enables hardware JTAG on these pins.

General-purpose pins (everything else — GPIO2/4-18/21/38/42-44): no fixed role on this module; each is routed through the GPIO matrix to its assigned peripheral (UART, I2C, PWM/LEDC, MCPWM, plain digital I/O). No datasheet restriction applies beyond the ones already called out above.

WIRING GUIDE (Block 5): place CdecES_C8+CdecES_C1 at the 3V3 pad first in the fanout. Keep the antenna edge clear (15mm). Route USB D+/D- as a matched pair, R_cc1/R_cc2 at the connector. SP7 is a bare 1-pin pad on GPIO45 — leave unpopulated unless deliberately used after a reset-safety review.

====================================================================================
7. MOTOR DRIVERS — 2× MKS TMC2209 V2.0 MODULES (BLOCK 6)
====================================================================================
2x8 sockets (SK1/SK2). Field-replaceable; eliminates QFN-28 thermal-pad failure mode.
StallGuard SG_RESULT feeds the PID mixing-stop — see Block 9 for the load-cell fallback.

7.1 Module specs & current  [TMC, TMCmod]
-----------------------------------------
Onboard sense resistors: 110 mΩ class (confirm by unpowered resistance check).
*** CURRENT CEILING (important): with 110 mΩ sense, full-scale current is
    I_RMS = 325 mV / (R_sense + 20 mΩ) x 1/√2 = 0.325/0.130 x 0.707 ≈ 1.77 A RMS
    → 2.5 A peak MAX [TMC current equation; TMCmod]. This holds for BOTH analog-VREF and
    UART IHOLD_IRUN with I_scale_analog=0 — the sense resistor sets the ceiling. You CANNOT
    reach 2.0 A RMS / 2.8 A peak on 110 mΩ; that needs ~95 mΩ. Baseline torque and StallGuard
    tuning at ~1.77 A RMS, or source lower-Rsense modules if more torque is required. ***
Current set: firmware uses UART IHOLD_IRUN with I_scale_analog=0 for repeatability. VREF
trimpot 0-2.5 V is the analog fallback; break VREF out to a test point (SP headers) to probe.

FABRICATED-BOARD INCIDENT (v2.51 hardware, drives §7.6 below): a TMC2209 module was removed
and reinserted with the board still powered. A visible spark occurred at the socket, and the
ESP32 module has heated abnormally on every power-up since (both USB and 24V). Suspected
mechanism: the 2×8 header has no keying, so a module can seat off-axis or row-shifted for a
brief moment during a live insert — VM (24V) and coil pins share the same header block as
EN/STEP/DIR/PDN_UART, all of which trace to ESP32 GPIOs with no series impedance between the
pin and the chip prior to v3.4. A momentary bridge is enough to exceed a GPIO's internal
ESD/clamp rating. DIAGNOSIS BEFORE RE-POWERING (do not just add protection and retry):
unpowered, measure 3V3-to-GND resistance; near-zero confirms a hard short. Isolate by lifting
the ESP32 module first (short disappears → ESP32 is the failure) then working outward
section by section if it persists. Bench-test the swapped TMC module standalone before
assuming it's undamaged. Do not re-power the full board repeatedly while still isolating —
see §7.6 for the protection added in response, and §13 for the new procedural checklist line.

7.2 UART addressing  [TMC: NODEADDR = MS1(bit0), MS2(bit1)] — CHANGED v3.4: field-jumpered
-----------------------------------------------------------------------------------------
Both modules share ONE PDN bus (multi-drop, distinguished by address). Address is now
field-selectable per module instead of hardwired, making U5 and U6 fully interchangeable
spares rather than fixed-position boards.
MS1/MS2 jumpers: 1×3 header + shunt on each pin, per module (4 headers total: JMP_MS1_T1,
JMP_MS2_T1, JMP_MS1_T2, JMP_MS2_T2), same convention as JMP_U5/JMP_U6 below. Center pin =
the module's MS1 (or MS2) pad; one end = 3.3 V via a 10 kΩ pull-up (R_M1S1/R_M1S2 for
module 1's MS1/MS2 pulls, R_M2S1/R_M2S2 for module 2's); other end = GND. No shunt = pin
floats to the TMC2209's internal pull-down (safe default = 0 on that bit).
*** PULL-UP MARGIN CAUTION: MS1/MS2 have an internal pull-down inside the TMC2209 chip
    itself. An external 10 kΩ pull-up fights this internal pull-down rather than driving a
    clean logic high — the resulting voltage depends on the internal pull-down's exact
    resistance, which was not confirmed in any source checked for this document. Before
    final value lock: either measure the resulting high-level voltage on the bench against
    VIH (~0.7×VIO ≈ 2.31 V), or pull the TMC2209 Rev 1.09 DC-characteristics table for the
    exact internal pull-down value. If marginal, drop the external pull-up to 2.2-4.7 kΩ. ***
VERIFY BEFORE ROUTING: confirm which physical module pin is genuinely MS1/MS2 against the
MKS V2.0 schematic, not generic third-party SilentStepStick documentation — this project has
already found one instance (§7.3 below) where this specific module's actual silkscreen
disagreed with generic community documentation for the family.

7.3 PDN_UART — 2-GPIO TX/RX pair — *** PIN ASSIGNMENT CORRECTED v3.4, FLIPPED FROM v3.3 ***
---------------------------------------------------------------------------------------------
GPIO4 = TX, GPIO44 = RX, joined by R_UART = 1 kΩ; the junction feeds the shared PDN bus.
R_PDN_UP = 10 kΩ, PDN bus → 3.3 V (one pull-up for the whole bus).
Firmware must suppress the TX echo on RX (standard for resistor-separated half-duplex).
*** CORRECTION: physical inspection of the actual MKS V2.0 module's own silkscreen shows
    "UART" labeled at pin 5, with R8 drawn between pin 5 and pin 4 — i.e. PIN 5 IS THE
    DIRECT PDN_UART NODE and pin 4 is on the far side of the module's own separator
    resistor R8. This is the OPPOSITE of every version through v3.3, which followed generic
    third-party SilentStepStick documentation (pin 4 = direct) rather than this specific
    module's own primary-source silkscreen. Trust the physical part's own markings over
    generic community writeups for a different board in the same family — same lesson as
    the LM2596 symbol-swap finding earlier in this project. ***
DEFAULT (corrected): use the main board R_UART; connect module PIN 5 (not pin 4). Per-module
3-pin jumper (JMP_U5/JMP_U6) selects pin 5 (direct, shunt 2-1, DEFAULT) vs pin 4 (via R8,
shunt 2-3, FALLBACK) as a no-rework option if this reading is ever found to be wrong on a
given unit. Silkscreen "PDN SEL: 1=DIRECT(PIN5) / 3=VIA R8(PIN4)". Never shunt both sides.
Verify R8's actual resistance with an unpowered resistance check across module pins 4-5
before relying on the fallback path — silkscreen confirms which pin is which, not R8's value.
GPIO PROTECTION (NEW v3.4): R_gpPDN_T1 / R_gpPDN_T2 (220 Ω each) placed in series between
the shared PDN bus and each module's jumper-selected pin — see §7.6.

7.4 SpreadCycle
---------------
Firmware writes GCONF.en_spreadcycle=1 at every boot and reads back to confirm. Confirm the
module's SPREAD/MS3 behavior against its schematic before assuming. Load-test on real
hardware before trusting SG_RESULT for the PID.

7.5 CLK pin
-----------
Per SilentStepStick-derived design CLK ties to GND on-module (internal oscillator selected).
[TMCmod / FYSETC: "add CLK pin, tie to GND via 0R"]. PENDING: confirm with an unpowered
continuity check (module CLK to GND) before removing any main-board CLK-tie. Do NOT confuse
with the AD9833 MCLK, which is the opposite requirement (AD9833 has no internal oscillator).

7.6 GPIO short-fault protection (NEW v3.4 — added directly in response to the §7.1 incident)
------------------------------------------------------------------------------------------------
A 220 Ω series resistor is now placed on every ESP32-to-TMC2209 control line, at the socket
boundary, for both modules — 12 resistors total:
  Module 1 (U5/SK1): R_gpSTEP_T1, R_gpDIR_T1, R_gpEN_T1, R_gpPDN_T1, R_gpMS1_T1, R_gpMS2_T1
  Module 2 (U6/SK2): R_gpSTEP_T2, R_gpDIR_T2, R_gpEN_T2, R_gpPDN_T2, R_gpMS1_T2, R_gpMS2_T2
PURPOSE: does not prevent a momentary bridge between VM/coil pins and a logic pin during a
mis-seated or hot-swapped module (that's a mechanical/procedural problem — see §13), but
limits the fault current that reaches the GPIO's internal ESD/clamp structure during such a
transient to something the pin can survive, rather than taking the fault directly.
ELECTRICAL IMPACT: negligible. 220 Ω into a GPIO's few pF of input capacitance gives a
sub-nanosecond RC time constant — no effect on STEP pulse timing even at high microstep
rates, and no meaningful voltage drop on EN/MS1/MS2 (near-zero static current into a CMOS
input). PDN_UART placement: in series between the shared bus and each module's
jumper-selected pin (§7.3), downstream of the existing R_UART/R_PDN_UP bus-level resistors.

7.7 VIO / VM
-----------
VIO (logic) is a SEPARATE pin from VM (motor) on this module [TMCmod: VCC_IO distinct from
VM]. VIO → 3.3 V (must match ESP32 logic; a mismatch here risks GPIO damage). VM → 24 V +
bulk caps: CdecT1_E / CdecT2_E (100 µF 50 V SMD radial, 8mm height — CHANGED v3.4 from THT,
placed BESIDE each socket, not underneath — an 8mm-tall SMD can does not clear the ~8.5mm
socket body plus module PCB stacked on top) + CdecT1_C / CdecT2_C (100 nF ceramic, close to
each socket's VM pin for HF bypass the electrolytic can't provide above ~1MHz). Verify VIO
against your schematic copy before power-up.

7.8 Pin mapping (verify against the MKS V2.0 schematic before routing)
---------------------------------------------------------------------
JP1: EN=GPIO7(U5)/GPIO10(U6) [10k pull-up main board] via R_gpEN_T1/T2;
     MS1/MS2=jumper-selected via JMP_MS1_T1/T2, JMP_MS2_T1/T2, through R_gpMS1_T1/T2 and
     R_gpMS2_T1/T2 (§7.2, §7.6); PDN=jumper-selected pin 5 default (§7.3) through
     R_gpPDN_T1/T2; CLK=GND (pending); STEP=GPIO5(U5)/GPIO8(U6) via R_gpSTEP_T1/T2;
     DIR=GPIO6(U5)/GPIO9(U6) via R_gpDIR_T1/T2.
JP2: VM=24 V+bulk (CdecT1_E/T2_E + CdecT1_C/T2_C); VIO=3.3 V; OA1/OA2/OB1/OB2 → J4/J5
     (confirm exact coil pin order against schematic — do not assume BTT ordering carries
     over); GND.
Spare 1-pin headers (SP1-SP6, unpopulated): DIAG x2, INDEX x2, VREF x2. Leave bare until
used (a populated-but-floating header is a noise antenna near the analog chain).

7.9 Mechanical
--------------
Module+socket taller than QFN-28. Confirm enclosure clearance against the MKS module's
dimensions, now also accounting for the beside-socket VM bulk caps (§7.7). Use retention
sockets or an adhesive dab given stepper proximity. No keying/shrouding added in v3.4 —
considered and deliberately deferred to a possible future mechanical-only revision rather
than holding up this pass; GPIO protection resistors (§7.6) and the powered-off swap
procedure (§13) are the v3.4 mitigation instead.

WIRING GUIDE (Block 6): VM bulk caps beside each socket (§7.7); VIO from 3.3 V; STEP/DIR/EN
per map, each through its 220Ω protection resistor (§7.6), with EN pull-ups; MS1/MS2 via
their jumpers and protection resistors; PDN via the jumper (pin 5 default) through its
protection resistor to the shared bus with R_UART at the MCU and R_PDN_UP once on the bus.
Motor coil outputs to J4/J5. Keep STEP/DIR away from the UAS analog top-layer region.

====================================================================================
8. UI IDC CONNECTOR — 20-PIN 2×10, TOUCH RESTORED (BLOCK 7)
====================================================================================
The breakout board (TFT + EC11 + 1 button + buzzer) and the 20-pin IDC pinout are BOTH unchanged from the original design — touch's three signals have always lived on ribbon pins 6, 11, and 12, and stay exactly there. What changes in v3.3 is only which ESP32 GPIO the main board connects to those three pins, plus one button removed. No breakout revision needed.

8.1 IDC pinout (main-board view)
--------------------------------

Pin  |  Signal   |  Main-board net  |  Notes                                                
--------------------------------------------------------------------------------------------
1    |  GND      |  GND             |  Red-stripe reference.                                
2    |  3.3V     |  3.3V            |                                                        
3    |  GND      |  GND             |                                                        
4    |  5V       |  5V              |  Buzzer supply.                                        
5    |  SPI_MOSI |  GPIO35          |                                                        
6    |  T_DO     |  GPIO46          |  CHANGED v3.3 — touch data out, restored (was NC in v3.2, was GPIO37 pre-v3.2). GPIO37 stays free for HX711_SCK — see §8.3.
7    |  SPI_CLK  |  GPIO36          |  20MHz, shared TFT + touch.                            
8    |  TFT_CS   |  GPIO39          |                                                        
9    |  TFT_DC   |  GPIO40          |                                                        
10   |  TFT_RST  |  GPIO41          |                                                        
11   |  T_CS     |  GPIO12          |  CHANGED v3.3 — touch chip select, restored. Reused from removed BTN2 — see §8.3.
12   |  T_IRQ    |  NC (main board) |  CHANGED v3.3 — touch runs polled, not interrupt-driven. See §8.3 for why.
13   |  EC11_A   |  GPIO16          |                                                        
14   |  EC11_B   |  GPIO17          |                                                        
15   |  EC11_SW  |  GPIO18          |                                                        
16   |  BTN1     |  GPIO11          |                                                        
17   |  BTN2     |  NC (main board) |  REMOVED v3.3 — one-button UI per team decision. Ribbon pin left connected on the breakout, just NC here.
18   |  BUZ_PWM  |  GPIO13          |                                                        
19   |  GND      |  GND             |                                                        
20   |  NC       |  —               |  Spare.                                                

8.2 Touch chip behavior on this bus
--------------------------------------
The XPT2046 shares SCK/MOSI with the ILI9341 on the same physical SPI bus and drives T_DO (MISO) only when its own CS is asserted low — otherwise it stays high-impedance, so it cannot interfere with TFT traffic when deselected. This is standard shared-bus SPI behavior, not something specific to this revision.

8.3 GPIO assignment rationale — why CS, DO, and IRQ landed where they did
------------------------------------------------------------------------------
This isn't an arbitrary pin reshuffle — it's built around one constraint: GPIO45 and GPIO46 are the board's only two strapping pins with any headroom left, and strapping pins are riskiest when an external pull resistor could be asserting a level during the boot-time strap sample.

T_CS commonly gets an external pull-up so the touch chip idles deselected before firmware configures anything — that makes it the "loudest" of the three touch signals at boot. It goes on GPIO12, freed by removing BTN2, which carries zero strapping role — so an external pull-up there is a complete non-issue.

T_DO (touch's MISO output) has no external pull-up in a typical XPT2046 wiring — the chip drives it push-pull when selected and leaves it high-impedance when not. That makes it the cleanest of the three signals, so it's the one placed on a strapping pin — GPIO46.

T_IRQ is usually open-drain with its own external pull-up (needed since it's open-drain), which makes it electrically similar to T_CS — exactly the kind of signal that risks fighting GPIO45's or GPIO46's boot-time strap read. Rather than accept that risk, T_IRQ is simply not connected on the main board as of v3.3. Touch presence is polled in firmware instead of interrupt-driven — a small, predictable firmware cost (§11.2), not a hardware risk. This also means GPIO45 stays completely unused, leaving it as the one genuinely spare, unclaimed pin on the entire board.

HX711's clock and data pins (GPIO37/42/21) are unaffected by any of this — they were never wired to the touch ribbon pins to begin with; they connect to the separate SK4/SK5 header sockets. See §10.2.

WIRING GUIDE (Block 7): J9 at the board edge, pin 1 marked. GPIO46 and GPIO12 route to IDC pins 6 and 11 respectively; IDC pin 12 (T_IRQ) and pin 17 (BTN2) are left unconnected on the main board — do not populate silkscreen footprints suggesting otherwise. Keep the 20-pin land pattern and silkscreen identical to the breakout's mating side, since the breakout itself is unchanged.

====================================================================================
9. MISCELLANEOUS CONNECTORS OUT (BLOCK 8)
====================================================================================
Ref | Label            | Type              | Wiring
----------------------------------------------------------------------------------------------
J1  | TX transducer    | SMA edge-launch   | IC1 chA → R_TL1 (47 Ω) + CinAC_C1 (100 nF) → J1.
J2  | RX transducer    | SMA edge-launch   | J2 → R_in (100 Ω) → Drx1 (BAV99) → IC2.
J3  | RPi UART         | JST-XH 3-pin      | 1:GND / 2:RX(GPIO48) / 3:TX(GPIO47), 921600.
J4  | Motor 1          | JST-PH 4-pin      | 1:OA1 2:OA2 3:OB1 4:OB2 (confirm order vs module).
J5  | Motor 2          | JST-PH 4-pin      | 1:OA1 2:OA2 3:OB1 4:OB2.
J6  | Limit M1         | JST-XH 2-pin      | 1:GND 2:GPIO14, Clim1_C1 (100 nF) debounce at MCU.
J7  | Limit M2         | JST-XH 2-pin      | 1:GND 2:GPIO15, Clim2_C2 (100 nF) debounce at MCU.
J8  | LED panel        | JST-XH 2-pin      | 1:5 V 2:GND.
J14 | PSU              | 5.0 mm screw term | CHANGED v3.4 (was 3.5mm) — higher current margin, heavier-gauge wire. 1:V+ (from inline fuse F1) 2:GND → F2 → Q1 (Block 1). Confirm 5.00mm (Phoenix PT-1,5/2-5,0) vs 5.08mm generic part before final BOM lock — either works on a 2-pin block, but pick one real P/N.
J15 | Turbidity I2C    | JST-XH 4-pin      | 1:3.3 V 2:GND 3:SDA(GPIO3) 4:SCL(GPIO43).
J16 | APDS9960 ext LED | JST-XH 2-pin      | 1:LED+ (3.3 V via R_LEDext 330 Ω) 2:GND.

MOTOR CONNECTOR CURRENT: JST-PH is ~2 A/contact. With the Block-6 ceiling the coil current is
<=1.77 A RMS, so PH is marginally OK (confirm the specific PH part's rating). The 2.8 A "peak"
that PH could not carry is not actually reachable on 110 mΩ sense — this ceiling de-risks the
connector.

TURBIDITY SENSING (on J15, off-board modules) [MAX, APDS]:
- APDS9960: I2C 0x39 (fixed), ALS clear-channel transmission mode (internal proximity path
  unused). External visible LED across the syringe, hardwired ON: 3.3 V → R_LEDext 330 Ω →
  J16 pin1 (anode); J16 pin2 → GND. Hardwiring removes software ambient subtraction — depends
  on enclosure light-sealing; flag for mechanical review. (Ref name R_LEDext assigned this
  pass — carried under its original functional name for several revisions before now.)
- MAX30102: I2C 0x57 (fixed), backscatter mode, own 660/880 nm LEDs, hardware ambient-light
  cancellation and 18-bit ADC [MAX]. No external LED.
- No address conflict (0x39 vs 0x57). Both modules self-decouple on their own PCBs; the main
  board supplies only the bus + one pull-up pair. Bring-up: I2C scanner should show 0x39+0x57.

WIRING GUIDE (Block 8): J15/J16 at the board edge near each other for a clean syringe cable
run. Limit/LED/UART connectors grouped by function. SMA edge-launches on the analog edge,
away from the switchers.

====================================================================================
10. LOAD-CELL FORCE SENSING — 2× HX711 (ADDED IN v3.2)
====================================================================================
Purpose: a hardware fallback for TMC2209 StallGuard SG_RESULT. Two load cells at the syringe contact/push point measure plunger force directly; if PDN_UART / SG_RESULT proves unreliable, the PID mixing-stop uses force instead. This is an independent sensing path with no UART dependency.

10.1 HX711 module facts  [HX711 datasheet, Avia Semiconductor]
-------------------------------------------------------------
Selected module: XFW-HX711 (green board, SKU MOD-BRE-007). Confirmed from the module photo: the MCU-side 4-pin header order, top to bottom, is GND, DT, SCK, VCC. The load-cell side is a 6-position screw terminal: E+, E-, A-, A+, B-, B+. An on-board RATE select is silkscreened "80Hz / 10Hz" with a 0Ω/solder-jumper between them — set this to 80Hz for force feedback (12.5ms latency vs. 100ms at 10Hz). This resolves the original "expose RATE" just-in-case item on its own, since the module already exposes it with no rework needed. Verify on a scope that DT produces ~80 samples/s once selected.

General HX711 behavior: supply range 2.6–5.5V at under 1.5mA, with a 24-bit sigma-delta ADC. It's a two-wire interface — SCK/PD_SCK is the clock in from the MCU, DT/DOUT is data out to the MCU. DT reads HIGH when the chip isn't ready and goes LOW once a sample is ready to read. A read consists of 25–27 PD_SCK pulses, where the exact count selects the channel and gain for the *next* reading: 25 pulses selects channel A at gain 128 (the default, ±20mV full-scale), 26 selects channel B at gain 32, and 27 selects channel A at gain 64.

On the XFW board, AVDD (bridge excitation) tracks VCC directly. At VCC=3.3V, a typical 2mV/V load cell produces roughly 6.6mV full-scale — comfortably inside the ±20mV gain-128 range, so 3.3V operation is fine.

Timing constraint worth building firmware around: if PD_SCK stays HIGH for more than 60µs, the chip powers itself down. A read burst must never be stalled mid-sequence by a long ISR — see §11 for how the compute budget protects this.

10.2 Wiring — XFW-HX711 modules on 4-pin sockets (SK4, SK5), shared clock
-----------------------------------------------------------------------
Each socket (SK4/SK5) matches the XFW header order GND/DT/SCK/VCC, top to bottom.

Module          |  GND  |  DT (DOUT)            |  SCK (PD_SCK)     |  VCC 
--------------------------------------------------------------------------
HX711 #1 (SK4)  |  GND  |  GPIO42 (HX711_1_DT)  |  GPIO37 (shared)  |  3.3V
HX711 #2 (SK5)  |  GND  |  GPIO21 (HX711_2_DT)  |  GPIO37 (shared)  |  3.3V

VCC is 3.3V so DT/SCK logic runs at 3.3V — direct to the ESP32, no level shifting needed. At 5V VCC, DT's high level would also be 5V and would damage the ESP32 GPIO — do not power these modules from 5V.

SCK is shared between both modules (both module SCK pins tie to GPIO37); DT is separate, one GPIO per module. Firmware clocks both chips together and reads both DT lines within the same loop — this needs a custom bit-bang driver, since standard HX711 libraries assume one dedicated clock pin per chip. Wait until both DT lines read LOW before starting a clock burst.

On the load-cell side, wire to the XFW screw terminals at E+/E- (excitation) and A+/A- (signal — channel A is the one in use). Keep load-cell leads short and twisted, and route them away from the switching regulators.

10.3 NC / spare breakout (just-in-case philosophy)
-------------------------------------------------
RATE is already exposed on the XFW board itself as the 80Hz/10Hz jumper (§10.1) — set to 80Hz, no main-board rework needed. Channel B (the B+/B- terminals, fixed gain 32) is unused and left available on the module's own screw terminal for a possible second or redundant sensor later — again, no board change required to use it if that need comes up.

WIRING GUIDE (Block 9): place SK4/SK5 near the board edge for the syringe cable run. GPIO37 (shared SCK) routes to both headers; keep the two DT lines short. The modules self-decouple; add a 100nF cap at each header's VCC pin if the specific module you receive lacks one onboard. Treat the force-sensor cable like an analog run — keep it away from the switchers and the STEP/DIR traces.

====================================================================================
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

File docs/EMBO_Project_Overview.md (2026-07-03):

# EMBO — Embolization Particle Sizing System

## Project Overview

**Last updated:** June 2026
**Status:** Active development, built by a small student/hobbyist engineering team spanning mechanical and electrical/software disciplines.

---

## What we are building

We are building a device called EMBO. It is an intelligent machine that helps doctors prepare medicine more consistently and safely before a type of procedure called embolization.

The device automates a preparation step that is currently done entirely by hand, with no quality checks, and produces different results depending on who does it and how experienced they are. Our goal is to make that step reliable, repeatable, and objective — regardless of who operates the device.

---

## What is embolization?

Embolization is a minimally invasive procedure used in interventional radiology. A doctor threads a thin catheter (tube) through a blood vessel and injects tiny particles to deliberately block blood flow to a targeted area. This is used to treat conditions like:

- Uterine fibroids (non-cancerous growths in the womb)
- Bleeding in the gut or after trauma
- Tumours — cutting off blood supply starves them
- Enlarged prostate (prostate artery embolization)

The particles used to block the vessels are called embolic agents. They are often made from gelatin foam — the same general material as gelatin desserts, but in medical grade sponge form. Common brand names include Gelfoam and Lyostypt.

---

## The problem we are solving

Before the procedure, a doctor or technician prepares the embolic agent by hand. The current process looks like this:

1. Cut a piece of gelatin foam into small chunks by hand
2. Place the chunks in a syringe with saline solution
3. Connect two syringes via a stopcock (valve)
4. Push the mixture back and forth between the syringes repeatedly until it reaches a "pudding consistency"
5. Inject into the patient

The problem is step 4. There is no measurement, no standard, and no objective quality check. Two doctors doing this side by side will produce slurries with completely different particle sizes. Particle size matters enormously — studies show that the wrong particle size can cause tissue death in the wrong place, or fail to block the target area effectively.

Nobody has ever built a device to measure and control particle size during this preparation step. We are building the first.

---

## How our device works

EMBO has three main jobs:

### 1. Automate the mixing

Two stepper motors drive the syringe plungers back and forth automatically, replacing the manual hand-pumping. The speed, stroke length, and number of strokes are all controlled precisely.

### 2. Measure the particle size

While mixing is happening, sensors measure the size of the particles forming in the slurry. We use two methods:

**a) Camera + Computer Vision**
A small camera looks through the syringe. AI software analyses each image and measures every individual particle, calculating statistics like the median size and spread (IQR — interquartile range).

**b) Ultrasound**
A pair of sensors clamp onto the outside of the syringe and fire sound waves through it. Larger particles absorb more sound energy. By measuring how much energy gets through, we can track whether particles are getting smaller as mixing continues.

### 3. Stop automatically at the right point

The device feeds the measurements into a control algorithm (PID loop) that decides when the particle size is in the correct range. The target size is adjustable per procedure (50–1000 micrometres, roughly 1 to 14 times the width of a human hair), since the ideal size depends on which blood vessels are being treated — see [The clinical context](#the-clinical-context) below. The doctor sets it on the touchscreen before starting; a typical default is around 300µm. When the measured size reaches the target, the device stops and alerts the doctor.

---

## The hardware — what the device is made of
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

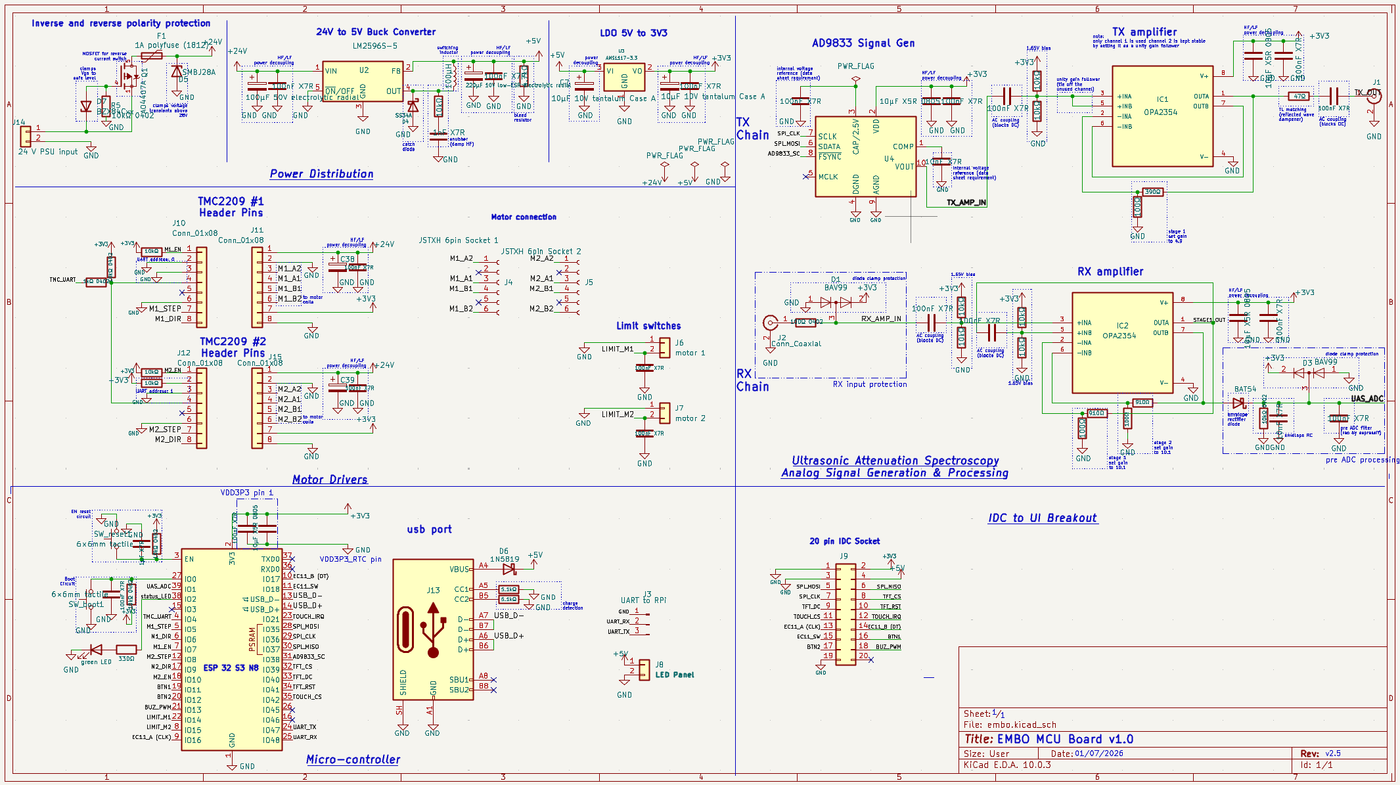
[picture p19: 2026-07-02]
assets/main PCB schematic.png

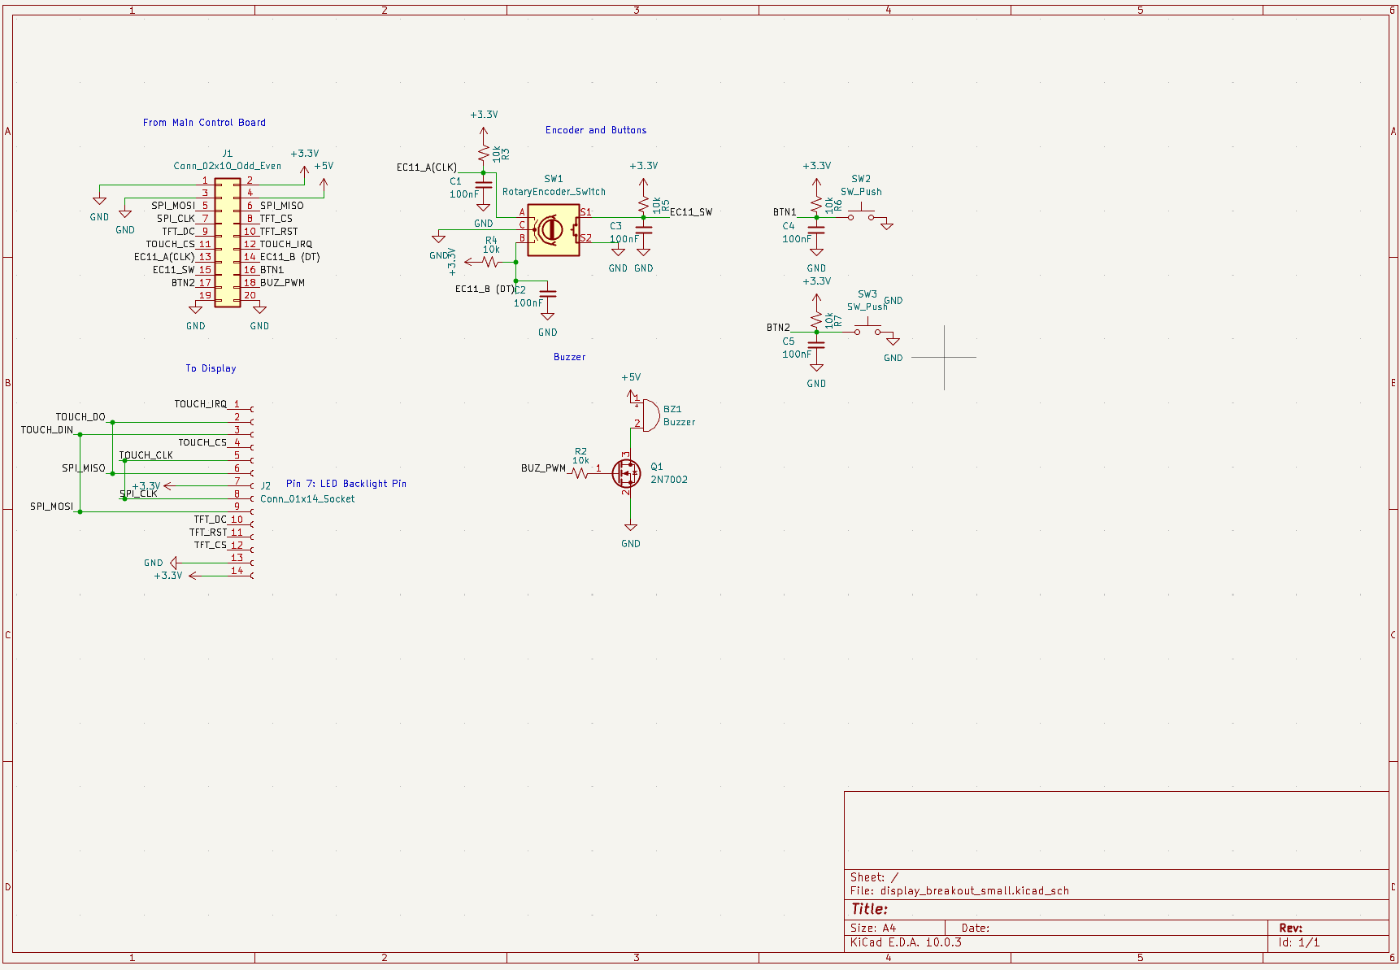
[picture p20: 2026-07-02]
assets/display breakout schematic.png

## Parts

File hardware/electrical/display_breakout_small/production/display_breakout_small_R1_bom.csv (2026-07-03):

Designator | Footprint | Quantity | Value | LCSC Part #
BZ1 | Buzzer_12x9.5RM7.6 | 1 | Buzzer
C1, C2, C3, C4, C5 | 0402 | 5 | 100nF
J1 | IDC-Header_2x10_P2.54mm_Vertical | 1 | Conn_02x10_Odd_Even
J2 | PinSocket_1x14_P2.54mm_Vertical | 1 | Conn_01x14_Socket
Q1 | SOT-23 | 1 | 2N7002
R2, R3, R4, R5, R6, R7 | 0402 | 6 | 10k
SW1 | RotaryEncoder_Alps_EC11E-Switch_Vertical_H20mm | 1 | RotaryEncoder_Switch
SW2, SW3 | SW_TH_Tactile_Omron_B3F-100x | 2 | SW_Push

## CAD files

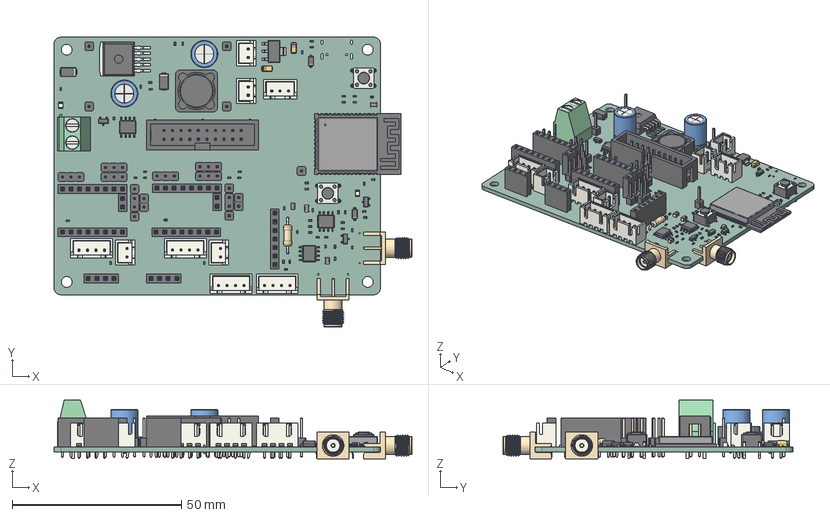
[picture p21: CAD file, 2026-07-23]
hardware/electrical/embo main MCU PCB v3_4/embo main MCU PCB.step
105.7 x 85.6 x 17.4 mm
R_0402_1005Metric x 31
PinSocket_1x08_P2.54mm_Vertical x 4
C_0805_2012Metric x 4
PinHeader_1x01_P254mm_Vertical x 13
SOIC-8_3.9x4.9mm_P1.27mm x 3
LED_0805_2012Metric x 2
C_0402_1005Metric x 20
D_SMA x 2
JST_B2B_XH_A x 4
PinHeader_1x03_P254mm_Vertical x 6
TerminalBlock_Phoenix_MKDS-1,5-2-5.08_1x02_P5.08mm_Horizontal
CP_EIA_3216_18_Kemet_A x 2
R_Axial_DIN0207_L63mm_D25mm_P1016mm_Horizontal
C_Radial_D80mm_H115mm_P350mm x 2
D_SOD-123 x 2
PinSocket_1x02_P2.54mm_Vertical x 2
SW_PUSH_6mm x 2
SOT-23 x 3
SRR1260
a648ce37-9c39-11ed-93f0-dde97e994e83_part
a648ce38-9c39-11ed-93f0-dde97e994e83_part
a648ce39-9c39-11ed-93f0-dde97e994e83_part
ESP32-S3-WROOM-1
JST_B3B_XH_A
PinSocket_1x04_P2.54mm_Vertical x 2
JST_B4B_XH_A x 4
IDC_Header_2x10_P254mm_Vertical
PinHeader_1x02_P254mm_Vertical x 2
SMA_Molex_73251-1153_EdgeMount_Horizontal x 2
PinSocket_1x07_P2.54mm_Vertical
SOT-223
embo_PCB

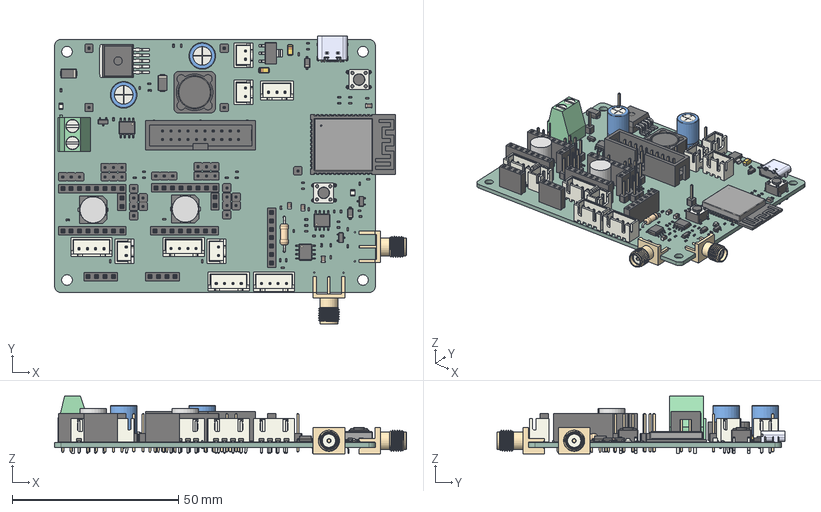
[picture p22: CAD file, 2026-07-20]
hardware/electrical/PCB STEP files/EMBO MAIN PCB v3.4.step
105.7 x 86.6 x 17.4 mm
R_0402_1005Metric x 31
PinSocket_1x08_P2.54mm_Vertical x 4
C_0805_2012Metric x 4
PinHeader_1x01_P254mm_Vertical x 13
SOIC-8_3.9x4.9mm_P1.27mm x 3
LED_0805_2012Metric x 2
C_0402_1005Metric x 20
D_SMA x 2
JST_B2B_XH_A x 4
PinHeader_1x03_P254mm_Vertical x 6
TerminalBlock_Phoenix_MKDS-1,5-2-5.08_1x02_P5.08mm_Horizontal
CP_EIA_3216_18_Kemet_A x 2
R_Axial_DIN0207_L63mm_D25mm_P1016mm_Horizontal
C_Radial_D80mm_H115mm_P350mm x 2
D_SOD-123 x 2
PinSocket_1x02_P2.54mm_Vertical x 2
SW_PUSH_6mm x 2
SOT-23 x 3
TYPE-C-31-M-12
SRR1260
a648ce37-9c39-11ed-93f0-dde97e994e83_part
a648ce38-9c39-11ed-93f0-dde97e994e83_part
a648ce39-9c39-11ed-93f0-dde97e994e83_part
ESP32-S3-WROOM-1
JST_B3B_XH_A
PinSocket_1x04_P2.54mm_Vertical x 2
JST_B4B_XH_A x 4
IDC_Header_2x10_P254mm_Vertical
PinHeader_1x02_P254mm_Vertical x 2
SMA_Molex_73251-1153_EdgeMount_Horizontal x 2
PinSocket_1x07_P2.54mm_Vertical
SOT-223
embo_PCB

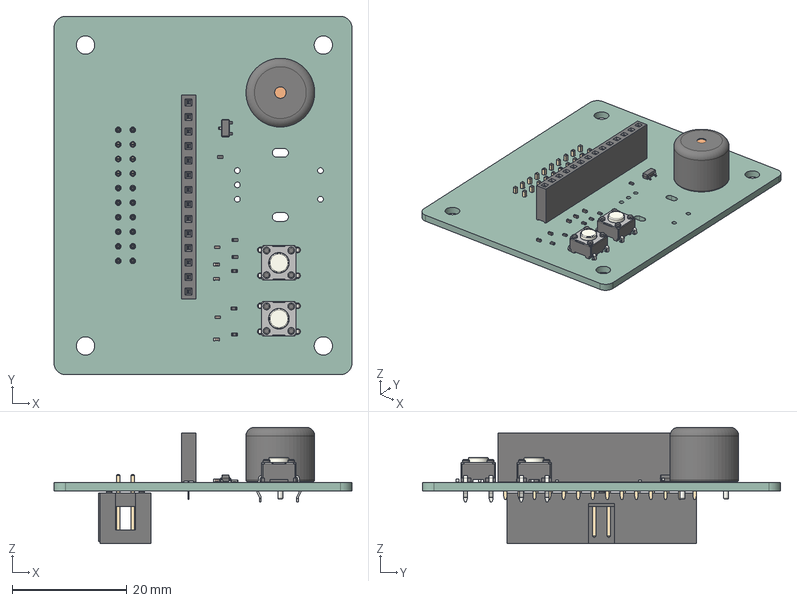
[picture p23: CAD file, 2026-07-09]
hardware/electrical/display_breakout_small/display_breakout_small.step
52.0 x 62.5 x 20.3 mm
R_0402_1005Metric x 6
SOT-23
C_0402_1005Metric x 5
SW_TH_Tactile_Omron_B3F-100x x 2
Buzzer_12x95RM76
PinSocket_1x14_P2.54mm_Vertical
IDC_Header_2x10_P254mm_Vertical
display_breakout_small_PCB

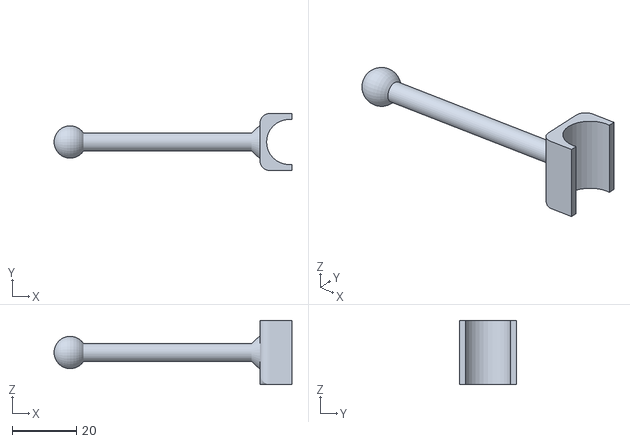
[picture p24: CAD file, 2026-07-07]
testing/7JUL_stabilised_mixing_video_testing/camera test mount.stl
74.3 x 17.8 x 20.0

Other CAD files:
hardware/electrical/display_breakout_small/.step
hardware/electrical/PCB STEP files/EMBO DISPLAY BREAKOUT.step
hardware/mechanical/Final Pure Assembly.f3z

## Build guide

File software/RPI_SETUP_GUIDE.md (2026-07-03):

# Raspberry Pi Setup & Development Guide (EMBO CV Pipeline)

A from-zero guide to getting a Raspberry Pi 5 running the EMBO CV pipeline, developed entirely from VS Code on Windows over SSH — no separate monitor/keyboard for the Pi, no copying files back and forth by hand.

If you've only done ESP32 development before, the mental model is different: the ESP32 has no OS, and "flashing" writes your compiled program directly into it. The Pi is a full Linux computer — you flash an *operating system* onto its SD card once, then develop on it like any other Linux machine over the network.

---

## What you need

- Raspberry Pi 5 + official power supply (5V/5A USB-C — an ordinary phone charger is usually not enough)
- microSD card (32GB+, A2-rated recommended) + a USB card reader for your Windows PC
- The USB 2.0 microscope camera (see `README.md`)
- A network your Pi and your Windows PC are both on (WiFi is fine)
- Windows PC with VS Code already installed

---

## 1. Flash the OS

"Flashing" here means writing a full Linux OS image onto the SD card — a one-time step, not something you repeat when your code changes.

1. Download **Raspberry Pi Imager** from raspberrypi.com on your Windows PC.
2. Insert the microSD card into your card reader.
3. Open Imager:
   - **Device:** Raspberry Pi 5
   - **OS:** Raspberry Pi OS (64-bit) — the standard Debian-based option is fine, no need for Lite unless you want to save space (Lite has no desktop GUI, which is fine since we're doing everything over SSH anyway)
   - **Storage:** your SD card
4. Click the **gear icon (⚙) / "Edit Settings"** before writing — this is the important part. It lets you pre-configure the Pi so it's usable immediately on first boot, with no monitor ever needed:
   - Set a **hostname** (e.g. `embo-pi` — you'll use this to find it on the network)
   - Set a **username and password**
   - Configure **WiFi** (SSID + password)
   - **Enable SSH** — tick "Enable SSH", use password authentication for now (you can switch to SSH keys later, see §4)
5. Write. This takes a few minutes and verifies the write afterward.

---

## 2. First boot

1. Insert the microSD card into the Pi, connect power.
2. First boot takes a minute or two longer than normal (resizing the filesystem, applying your Imager settings).
3. From a Windows PowerShell window, check the Pi is reachable:
   ```powershell
   ping embo-pi.local
   ```
   Replace `embo-pi` with whatever hostname you set. If this doesn't resolve, find its IP address from your router's connected-devices list instead.

---

## 3. Connect over SSH (quick sanity check)

Before bringing in VS Code, confirm plain SSH works from PowerShell:

```powershell
ssh username@embo-pi.local
```

Accept the host key prompt (first connection only), enter your password. You should land at a Linux shell prompt on the Pi. Type `exit` to disconnect. If this works, VS Code Remote-SSH will too — it uses the same connection underneath.

---

## 4. Set up VS Code Remote-SSH

This is what lets you keep working entirely inside VS Code on Windows, with the Pi's filesystem and terminal available directly in the editor.

1. In VS Code, install the **Remote - SSH** extension (publisher: Microsoft, extension ID `ms-vscode-remote.remote-ssh`).
2. Press `Ctrl+Shift+P` → **Remote-SSH: Connect to Host...** → **Add New SSH Host** → enter `username@embo-pi.local`.
3. Connect. VS Code opens a new window connected to the Pi — the bottom-left corner will show the hostname, confirming you're remote.
4. **Optional but recommended — switch to SSH key auth** so you're not typing a password every time:
   ```powershell
   ssh-keygen -t ed25519            # on Windows, if you don't already have a key
   ssh-copy-id username@embo-pi.local   # or manually append your .pub key to ~/.ssh/authorized_keys on the Pi
   ```
   After this, `ssh embo-pi.local` and VS Code Remote-SSH both connect without a password prompt.

From here on, **everything below happens inside that VS Code remote window** — open a terminal with `` Ctrl+` `` and it's a real shell running on the Pi, not Windows.

---

## 5. Get the EMBO repo onto the Pi

The Pi needs its own clone of the repo — your Windows checkout and the Pi's checkout are two separate copies that you keep in sync via git, the same as you would between any two machines.

```bash
git clone <your-repo-url> ~/EMBO
cd ~/EMBO/software/cv-pipeline
```

If the repo is private, you'll need to set up a GitHub credential on the Pi too (a personal access token, or an SSH key added to your GitHub account — same idea as §4's key setup, just for GitHub instead of SSH login).

---

## 6. Python environment

Raspberry Pi OS (Debian Bookworm and later) blocks `pip install` directly into the system Python — this is intentional (Debian calls it an "externally managed environment") and you'll hit an error if you try. Use a virtual environment instead:

```bash
cd ~/EMBO/software/cv-pipeline
python3 -m venv .venv
source .venv/bin/activate
pip install -r requirements.txt
```

`source .venv/bin/activate` needs to be run again every time you open a new terminal (VS Code will usually offer to do this automatically once it detects the `.venv` folder — accept it, or select the interpreter manually via `Ctrl+Shift+P` → **Python: Select Interpreter**).

---

## 7. Hardware bring-up checks

Do these before trying to run `main.py` against real hardware — they isolate "is the hardware even visible to Linux" from "does the pipeline code work."

**Camera:**
```bash
sudo apt install v4l-utils   # one-time, provides v4l2-ctl
ls /dev/video*               # the USB microscope camera should show up as /dev/video0 (or similar)
v4l2-ctl --list-formats-ext  # lists actual supported resolutions/fps — check against config.py
```

**UART (for the ESP32 link):** the Pi's primary UART is disabled by default and its pins are normally used for a serial console login, which conflicts with our use as a data link. Free it up:
```bash
sudo raspi-config
```
Navigate to **Interface Options → Serial Port** → answer **No** to "login shell over serial", **Yes** to "enable serial port hardware". Reboot after. Then confirm the device exists:
```bash
ls -l /dev/serial0   # should exist, usually a symlink to /dev/ttyAMA0 (Pi 5 uses the RP1 chip — mapping may differ from older Pis, confirm this actually matches config.py's UART_PORT)
```

**Permissions:** your user needs to be in the right groups to access the camera and serial port without `sudo`:
```bash
sudo usermod -aG video,dialout $USER
```
Log out and back in (or reboot) for group changes to take effect.

---

## 8. Run it

```bash
cd ~/EMBO/software/cv-pipeline
source .venv/bin/activate
python main.py
```

Right now (per `SOFTWARE_TODO.md`), this exercises camera capture + the UART link to the ESP32 — you should see the firmware's BLE log show `"RPi: median=X iqr=Y um"` disappear and instead get a `"CV: detection/sizing not implemented yet"` status line, since `detection.py`/`sizing.py` are still stubs. That's expected — it's proof Layer 1 (camera + UART) works, which is the current milestone.

Stop with `Ctrl+C`.

---

## Common gotchas

- **`pip install` fails with "externally-managed-environment"** → you forgot to activate the venv (§6). Always `source .venv/bin/activate` first.
- **`/dev/video0` doesn't appear** → try a different USB port (some Pi 5 USB3 ports draw more power than others; a cheap UVC camera occasionally needs a powered hub). Check `dmesg | tail` after plugging in for kernel-level errors.
- **`/dev/serial0` permission denied** → you're not in the `dialout` group yet, or haven't logged out/in since adding yourself (§7).
- **VS Code Remote-SSH "could not establish connection"** → usually the Pi's hostname isn't resolving. Try connecting with the raw IP address instead of `embo-pi.local` as a fallback.
- **Pi feels slow over WiFi for file operations** → normal for the first index/extension-install after connecting; subsequent sessions are much faster since VS Code caches its server on the Pi.

---

## Where to go next

Once hardware bring-up (this guide) is done, actual pipeline development tasks — camera calibration, dye/lighting trials, the segmentation model, sizing math — are tracked in [`../SOFTWARE_TODO.md`](../SOFTWARE_TODO.md), not here. This guide only covers "how do I get onto the Pi and run code," not "what code to write."

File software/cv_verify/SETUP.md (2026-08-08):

# Pi Zero 2W Setup Guide (cv_verify)

Written for someone coming from MCU/ESP32 flashing, not Linux. The mental model
difference: an ESP32 has no OS — "flashing" writes your program directly into
its flash. A Pi is a full Linux computer — you flash an *operating system* onto
its SD card once, then you develop on it like any networked Linux machine,
copying/running code the same way you would on a server. You don't re-flash
the OS every time your Python changes.

This mirrors `../RPI_SETUP_GUIDE.md` (your friend's Pi 5 guide) — SSH, VS Code
Remote-SSH, and venv setup are identical steps. Only the parts that differ for
Zero 2W are called out explicitly below; where a step is unchanged, this guide
just points at the equivalent section in that doc instead of repeating it.

---

## What you need

- Raspberry Pi Zero 2 W + a good 5V/2.5A micro-USB power supply
- microSD card (32GB+) + USB card reader for your Windows PC
- **Zero-format CSI camera adapter cable** — the Zero 2W's camera connector is
  physically smaller than a Pi 5/4's. The Global Shutter Camera's stock ribbon
  will not plug in directly; you need the Zero-specific adapter cable (sold by
  the same vendors as the camera, look for "Camera Cable for Raspberry Pi Zero").
  **Order/confirm this before anything else** — it's the one item that blocks
  physically connecting the camera at all.
- OV9281-110 camera module (per the earlier discussion — confirm this is the
  unit you have in hand, not the Global Shutter Camera the old docs assumed;
  connector/driver notes below assume OV9281)
- A network your Pi and Windows PC are both on (WiFi)
- Windows PC with VS Code already installed

---

## 1. Flash the OS

Same tool as the Pi 5 guide (Raspberry Pi Imager), different choices:

1. Download **Raspberry Pi Imager** from raspberrypi.com.
2. Insert the microSD card.
3. Open Imager:
   - **Device:** Raspberry Pi Zero 2 W
   - **OS:** Raspberry Pi OS **Lite (64-bit)** — no desktop GUI. The Zero 2W has
     512MB RAM total; a desktop environment sitting idle in the background isn't
     worth the memory pressure when everything here happens over SSH anyway.
   - **Storage:** your SD card
4. Click the **gear icon (⚙) / "Edit Settings"** before writing:
   - **hostname** (e.g. `embo-cv`)
   - **username and password**
   - **WiFi** (SSID + password) — the Zero 2W only has WiFi, no Ethernet port,
     so this step isn't optional the way it might be on a 5
   - **Enable SSH** (password auth for now)
5. Write and wait for verification to finish.

---

## 2. First boot + SSH

Same as `../RPI_SETUP_GUIDE.md` §2–3:

```powershell
ping embo-cv.local
ssh username@embo-cv.local
```

The Zero 2W's quad-core A53 is noticeably slower to boot than a Pi 5 — give it
an extra minute on first boot before worrying it's stuck.

---

## 3. VS Code Remote-SSH

Identical to `../RPI_SETUP_GUIDE.md` §4 — install the Remote-SSH extension,
connect to `username@embo-cv.local`, optionally switch to key auth. No
Zero-specific differences here.

One thing worth knowing going in: VS Code's remote server process itself uses
a non-trivial slice of that 512MB RAM. If things feel sluggish, prefer doing
heavier one-off Python work (e.g. batch-testing detection.py once it exists)
via a plain SSH terminal rather than through VS Code's remote extensions, and
close file-heavy language-server features you don't need for Python editing.

---

## 4. Get the repo onto the Pi

```bash
git clone <your-repo-url> ~/EMBO
cd ~/EMBO/software/cv_verify
```

Same private-repo credential setup as the Pi 5 guide if needed.

---

## 5. Python environment

```bash
cd ~/EMBO/software/cv_verify
python3 -m venv .venv
source .venv/bin/activate
pip install -r ../requirements.txt   # shared with cv-pipeline for now — pyserial, opencv-python, numpy
```

Same "externally-managed-environment" note as the Pi 5 guide applies — always
activate the venv first.

---

## 6. Camera bring-up (OV9281-110)

Different from the Pi 5 guide's UVC (`/dev/video0`) instructions — this is a
CSI camera, so it goes through `libcamera`, not `v4l2` generic UVC drivers.

```bash
libcamera-hello --list-cameras
```

should list the OV9281 sensor. If it doesn't show up:

- [ ] Confirm the Zero-format adapter cable is seated correctly at **both** ends
  (camera module and Pi board) — this is the single most common CSI "camera not
  detected" cause, more often than a software/driver issue.
- [ ] Check `/boot/firmware/config.txt` has camera auto-detection enabled
  (`camera_auto_detect=1`, on by default on recent Raspberry Pi OS) — the OV9281
  isn't one of the "official" Pi camera modules, so on older OS images you may
  need an explicit `dtoverlay=ov9281` line instead of relying on auto-detect.
  Check `dmesg | grep -i ov9281` after boot to see whether the kernel found the
  sensor at all — that tells you whether this is a config.txt/driver problem or
  a physical connection problem.
- [ ] Confirm you're running a 64-bit OS with a recent `libcamera`/`rpicam-apps`
  package — `sudo apt update && sudo apt full-upgrade` if the image is old.

Once detected, capture a test frame to confirm end-to-end:

```bash
libcamera-still -o test.jpg --timeout 2000
```

Copy `test.jpg` back to Windows (VS Code's remote file explorer, or `scp`) and
eyeball it — this is your Layer-1 optical sanity check before writing any
Python capture code.

---

## 7. UART bring-up (for the ESP32 link)

This is the step where Zero 2W is actually **simpler** than the Pi 5 your
friend was fighting with (RP1-chip UART-mapping uncertainty, `SOFTWARE_TODO.md`
task 2) — the Zero 2W's UART behaves like the well-documented Pi 3/4 story.

The catch on *any* Pi with onboard WiFi/Bluetooth (Zero 2W included): the good
PL011 UART is wired to the Bluetooth chip by default, and GPIO14/15 only get
the second-rate mini-UART (`ttyS0`), whose baud clock is tied to the CPU
frequency — not stable enough for our 921600 baud link. Fix it:

```bash
sudo raspi-config
```
Interface Options → Serial Port → **No** to "login shell over serial", **Yes**
to "enable serial port hardware". Then, edit `/boot/firmware/config.txt` and add:

```
dtoverlay=disable-bt
```

```bash
sudo systemctl disable hciuart
sudo reboot
```

After reboot, confirm:

```bash
ls -l /dev/serial0    # should exist, symlinked to /dev/ttyAMA0
```

`/dev/ttyAMA0` is now the real PL011 UART on GPIO14/15 — matches
`cv_verify`'s planned `UART_PORT` and needs no per-Pi-model uncertainty caveat
the way the Pi 5 did.

**Wiring reminder** (from the earlier JST discussion): ESP32 GPIO47 (TX) →
Pi GPIO14 pin 8 is wrong — cross them. ESP32 TX → **Pi RXD (GPIO15, pin 10)**,
ESP32 RX → **Pi TXD (GPIO14, pin 8)**, GND → GND. Both sides 3.3V, no level
shifter.

---

## 8. Permissions

```bash
sudo usermod -aG video,dialout $USER
```
Log out and back in (or reboot) for this to take effect — needed before Python
can open the camera or `/dev/serial0` without `sudo`.

---

## Verification gate for this layer

Before writing any `cv_verify` Python code, confirm all of these independently:

- [ ] `libcamera-hello --list-cameras` shows the OV9281
- [ ] `libcamera-still` produces a viewable, correctly exposed test image
- [ ] `ls -l /dev/serial0` resolves to `/dev/ttyAMA0`
- [ ] From the Pi, `echo "SIZE 250 30" > /dev/serial0` (or a short pyserial
  script) results in the ESP32's BLE log showing `RPi: median=250 iqr=30 um`
  (`firmware/esp32/src/rpi_uart.cpp:36`) — this is the same integration gate
  called out in `TODO.md` Layer 1, and it's worth doing manually here before
  any Python capture/detection code exists, so a UART wiring problem and a
  software bug are never debugged at the same time.

---

## Common gotchas

- **`libcamera-hello` says "no cameras available"** → almost always the ribbon
  cable, not software. Reseat both ends, check the blue/silky side faces the
  right direction (varies by connector, check the cable's own orientation
  markings).
- **`/dev/serial0` missing after the raspi-config step** → you likely skipped
  the `dtoverlay=disable-bt` line or didn't reboot after adding it — WiFi/BT
  settings changes don't take effect until reboot.
- **UART sends nothing / firmware never logs a packet** → double check the
  TX/RX cross-over (a very common wiring mistake is connecting TX→TX,
  RX→RX instead of crossed) and that both ends actually share a GND.
- **Pi feels slow generally** → expected on 512MB RAM; avoid running VS Code
  Remote-SSH and a heavy Python process simultaneously if things stall, prefer
  a plain SSH terminal for running scripts.

---

## Where to go next

Once every box in this file's verification gate is checked, move to
`TODO.md` Layer 1 (request/reply UART link) — that's where `link.py` gets
written.

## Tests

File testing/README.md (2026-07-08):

# Files used for Experimental Testing

# syringe_force_baseline
Firmware for testing baseline syringe force. Based on ESP32 Platform, uses a loadcell and HX711 loadcell amplifier. 
(still a work in progress)

# 3JUL_preliminary_microscope_testing
Write-up of the first hands-on microscope + backlighting test on Lyostypt and dental hemostatic foam. See [`3JUL_preliminary_microscope_testing/2026-07-03_preliminary_microscope_testing.md`](3JUL_preliminary_microscope_testing/2026-07-03_preliminary_microscope_testing.md) — this test is the origin of `docs/EMBO_UAS_CV_Technical_Advisory.txt`.

# 3JUL_stopcock_aperture_testing
Follow-up test moving the camera to the stopcock aperture (per the advisory's Problem B fix). Confirms overlap is avoided, but continuous lighting (smartphone backlight and the camera's built-in LED, both tested) causes significant motion blur — see [`3JUL_stopcock_aperture_testing/2026-07-03_stopcock_aperture_testing.md`](3JUL_stopcock_aperture_testing/2026-07-03_stopcock_aperture_testing.md). Confirms strobed illumination is now required, not optional, for `software/SOFTWARE_TODO.md` task 12.

# 7JUL_stabilised_mixing_video_testing
3D-printed camera mount (replacing handheld positioning) + red-filtered LED backlight, stabilised mixing video recorded for hemostatic sponge and Lyostypt (linked via Google Drive). See [`7JUL_stabilised_mixing_video_testing/2026-07-07_stabilised_mixing_video_testing.md`](7JUL_stabilised_mixing_video_testing/2026-07-07_stabilised_mixing_video_testing.md) — observations pending video review.

# 8JUL_piezo_transducer_oscilloscope_testing
Preliminary test of signal transmission and attenuation between two piezoelectric transducers sandwiching a finger, using a signal generator and oscilloscope. A clear 1MHz signal (4.76V Pk-Pk in, 211mV Pk-Pk out) is received through the finger with readable attenuation. See [`8JUL_piezo_transducer_oscilloscope_testing/2026-07-08_piezo_transducer_oscilloscope_testing.md`](8JUL_piezo_transducer_oscilloscope_testing/2026-07-08_piezo_transducer_oscilloscope_testing.md).

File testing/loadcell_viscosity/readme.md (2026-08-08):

Things to note for loadcell data processing
Data is in the folder "cleaned data"
Format 

example line of data : [490772] Motion > Test Both Motors: stroke 1 progress - left=14801 right=1199 - force1=-1730.63g force2=-0.40g

1. First 6 letter number [490772] is the timestamp (in milliseconds) of when the data was recorded. Due to HW limitations, exact time cannot be logged. 
2. left=14801 right=1199 is the position of the loadcell. Loadcell position is based on motor steps. When the loadcell is homed i.e. at the 
    top left and top right respectively, the motor step position is set as 0, as per the homing procedure. Max travel distance currently in 
    the firmware is 16000 motor steps (yet to calculate into physical distance).
3. force1=-1730.63g force2=-0.40g is the force/weight/mass measured by the loadcells. Left loadcell corresponds to force1, right loadcell corresponds to force2.

Naming of the files: 1s means 1 stroke, stroke is defined based on the old definition of 2 pumps. Due to some firmware issues, sometimes the logging crashed 
after a stroke was completed, hence data was collected in multiple files for 3s,5s and 9s. (for some reason it worked well during 7s) 9s1 means first file for 9s. 9s2,9s3... 
are the next files, arranged in order of which file was saved first i.e. 9s1 contains first few strokes, 9s7 contains last stroke data.

Hope this is clear enough

"loadcelldatacleaner.py" removes extra irrelevant rows of serial data that was collected during the collection process.

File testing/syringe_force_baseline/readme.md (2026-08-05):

steps to use
1. plug into the LEFT usbc port of the esp, esp should power on 
2. left button (rst button on esp) resets the whole esp, acts as a tare (because it tares everytime it restarts)
3. run the file fetch_csv.py, it should say Connected, waiting for test
4. right button (boot button on esp) starts the test, it should start logging data to the laptop
5. press the right button to stop the test
6. data should be logged in a csv in test_results folder
7. can use plotresults.py to plot into a graph (requires editing of the python script to open the correct file)
8. if these data collection methods are not good enough / not to your needs then pls generate another tyvm

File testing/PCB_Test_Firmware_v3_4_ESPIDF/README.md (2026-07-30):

# PCB_Test_Firmware_v3_4_ESPIDF

**ESP-IDF-native variant** of `testing/PCB_Test_Firmware_v3_4/` — identical
behavior/pinout/protocol, built directly against `framework = espidf`
(PlatformIO) instead of the Arduino core. No `Arduino.h` anywhere in `src/`
or `include/`; every Arduino API used by the original (GPIO, timing, ADC,
I2C, SPI, LEDC, UART, BLE) was reimplemented against native ESP-IDF drivers.
See `testing/PCB_Test_Firmware_v3_4/` for the Arduino-framework sibling this
was ported from — keep both in sync if you change behavior, since they're
meant to be functionally identical.

## Notes before building

- **Build with `pio run`** (PlatformIO Core). First run downloads the
  ESP-IDF toolchain (~10+ minutes, several hundred MB) via
  `pioarduino`'s `framework-espidf` package (pinned to ESP-IDF 5.1.4 as of
  this port).
- **Windows + spaces in the path**: ESP-IDF's CMake build system rejects any
  whitespace in the full path (both the project path *and* the PlatformIO
  core/package directory, e.g. `C:\Users\Jane Doe\...`). If your checkout or
  `~/.platformio` lives under a spaced path, work around it with `subst`
  (map a drive letter to a space-free path) rather than a directory
  junction/symlink — junctions get transparently resolved back to the real
  (spaced) path by Windows and by Git, which reintroduces the problem (and,
  for junctions pointed straight at the project subfolder rather than the
  repo root, breaks `git`'s upward directory search for version info).
  `subst Z: "C:\Users\Jane Doe\path\to\repo"` (mapped to the repo root, not
  just the project folder) plus `PLATFORMIO_CORE_DIR` pointed at a similarly
  `subst`-mapped drive for `~/.platformio` is the combination that works.
- `version.txt` (checked into this project) pins `PROJECT_VER` so ESP-IDF's
  build system doesn't try `git describe` on the project directory — useful
  regardless of the whitespace/subst situation above, since this project
  directory isn't a git repo root itself.
- `sdkconfig.defaults` configures the native NimBLE BLE host (`CONFIG_BT_*`)
  and flash size/partition table (4MB single-app, matching the
  ESP32-S3-WROOM-1-N4 on this board). `sdkconfig.esp32-s3` is a generated
  build artifact (gitignored) — delete it and re-run `pio run` if sdkconfig
  ever gets out of sync with `sdkconfig.defaults`.
- **LovyanGFX** builds cleanly against ESP-IDF as-is — `src/hal/LGFX_Config.h`
  needed no framework-specific changes; LovyanGFX detects the absence of
  `ARDUINO` and uses its native ESP-IDF platform code path itself.
- The trickiest ports were the hand-rolled `src/hal/tmc2209_uart.*` TMC2209
  UART register driver (replacing TMCStepper) and the native NimBLE GATT
  server in `src/ble/ble_service.cpp` (replacing NimBLE-Arduino) — see
  comments in those files. Neither has been verified against real hardware
  (no board attached in this environment) — only that they compile and link
  cleanly and that the protocol-level bit positions/CRC/UUID-byte-order were
  worked out by hand against datasheet/library references.

---

Bring-up firmware + Web Bluetooth dashboard for the **v3.4** EMBO main board
(`docs/EMBO_PCB_Design_Brief_v3_4.txt`). Forked from `PCB_Test_Firmware`
(the v2.51-board test rig) with two additions:

- **Load-cell force sensing** — 2x HX711, shared clock, bit-banged driver
  (`src/hal/force_sensor.*`), per brief §10.
- **Turbidity sensing** — APDS9960 (ALS, 0x39) + MAX30102 (backscatter,
  0x57) on the shared I2C bus (`src/hal/turbidity.*`), per brief §9.

`src/hal/{motors,homing,tmc_uart_stream,bus_probe,uas_sensor}.*` and the BLE
transport are carried over from the v2.51 rig — v3.4's changes (220R GPIO
protection resistors, MS1/MS2 address jumpers, PDN pin4/5 correction, F2
backstop fuse, THT buttons/gain resistor) are passive/hardware hardening and
don't move any GPIO assignment this firmware depends on. `config.h` documents
the full v3.4 pin map used here.

BLE UUIDs and the advertised name (`EMBO-PCB-Test-v3.4`) are distinct from
the v2.51 rig's, so both boards' dashboards can be open side-by-side without
cross-connecting.

## Dashboard

Open `web/index.html` in Chrome or Edge (Web Bluetooth required) while the
board is powered and advertising. Every sensor on the v3.4 board shows both
its live numeric reading and a rolling strip-chart: UAS envelope, both load
cells, both turbidity channels, both StallGuard results, both limit
switches, and motor position/homing state. Motor jog/home controls are
carried over unchanged from the v2.51 dashboard.

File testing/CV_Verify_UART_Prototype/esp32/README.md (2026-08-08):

# Firmware — ESP32-S3

Arduino/C++ firmware for the EMBO ESP32-S3-WROOM-1-N4 control board (v3.4).
Built and flashed with PlatformIO inside VS Code.

## What this firmware does

| Module | File | Status |
|---|---|---|
| TMC2209 UART init, SpreadCycle, StallGuard | `src/motors.cpp` | ✅ |
| LEDC step generation, limit switch ISRs | `src/motors.cpp` | ✅ |
| Homing routine + stroke counter | `src/motors.cpp` | ✅ |
| AD9833 1MHz DDS init, UAS ADC calibration | `src/uas.cpp` | ✅ |
| Turbidity (APDS9960 ALS + MAX30102 backscatter) | `src/turbidity.cpp` | ⚠️ implemented but **currently disabled** — `turbidity_init()`/`turbidity_update()` are commented out in `main.cpp` (sensors not physically connected on the current bench setup), so this fusion channel reads 0 permanently until re-enabled |
| Force sensing (HX711 x2, shared clock) | `src/force_sensor.cpp` | ✅ read path — fusion input, calibrated scale factors in `calibration.h`. Automatic e-stop on over-force has been **removed** (see Safety below) — `force_sensor_estop_tripped()` still exists but nothing calls it |
| RPi UART receive + on-demand capture protocol | `src/rpi_uart.cpp` | ✅ |
| Sensor-to-physical-unit + 9-point fusion calibration | `src/calibration.cpp` | ✅ structure in place — `SENSOR_CAL_TABLE` is still all placeholders pending the 9-syringe bench session, see `../CALIBRATION.md`. With turbidity disabled and the table unpopulated, fusion currently has at most 2 live channels (UAS, force) and 0 trusted channels until real data is entered |
| Mixing scheduler (closed loop on fused sensor estimate) | `src/scheduler.cpp` | ✅ structure in place — depends on `SENSOR_CAL_TABLE` being real data |
| TFT display (LovyanGFX) + encoder + BTN1 + touch (secondary) | `src/ui.cpp`, `src/ui/screens/*` | ✅ menu-tree UI, see "Operational workflow" below |
| Shared TFT drawing helpers | `src/ui/ui_display.cpp` | ✅ |
| Shared input layer (EC11 ISR, BTN1/EC11-switch debounce, touch tap polling) | `src/ui/ui_input.cpp` | ✅ |
| Session-only mixing options (agent, syringe type, target type) | `src/mixing_options.cpp` | ✅ **cosmetic/labeling only, confirmed** — no calibration constant reads these; no viscosity calibration exists anywhere in the codebase |
| Session-only sound on/off flag | `src/sound_settings.cpp` | ✅ currently has no observable effect (the only sound, a boot chirp, fires before this setting is reachable) — exists for future UI tones |
| Load-cell flash logging (LittleFS) | `src/data_logger.cpp` | ✅ buffers HX711 samples to `/loadcell.csv` for a more trustworthy record than the live stream; controlled by the binary BLE `LOG_CTRL` characteristic, see below |
| NimBLE wireless debug UART (text console) | `src/ble_debug.cpp` | ✅ |
| NimBLE binary telemetry service (second, separate service) | `src/ble_binary_telemetry.cpp` | ✅ built to match a specific bench HTML dashboard, see "BLE binary telemetry" below — not documented elsewhere, and distinct from both the text console above and from `testing/PCB_Test_Firmware_v3_4`'s dashboard |

See [FIRMWARE_TODO.md](../FIRMWARE_TODO.md) for the full build-up task list and hardware checklist, and [`../CALIBRATION.md`](../CALIBRATION.md) for the one place to tweak every raw-sensor-to-physical-value mapping as calibration data comes in.

**This IS closed-loop — just not on CV.** UAS attenuation, APDS9960 turbidity, MAX30102 turbidity, and load-cell force are each calibrated against a 9-point bench dataset (known particle sizes from 9 reference syringes, see `CALIBRATION.md` §5) and fused into a live size estimate the scheduler checks after every stroke. **CV is the one signal that's optional and on-demand** — the RPi only captures a frame and runs CV when the ESP32 explicitly asks (`rpi_request_capture()`); the doctor can trigger it (encoder long-press) to independently double-check the fusion's result, but it never drives the stop decision itself.

**Currently, in practice, fusion has less than its full four channels.** Turbidity is disabled at the source (see table above) and `SENSOR_CAL_TABLE` is unpopulated, so `calib_estimate_particle_size_um()` currently returns `numChannelsUsed == 0` regardless — the scheduler can only stop via `MIXING_MAX_STROKES_SAFETY_CAP` until the 9-syringe bench session runs (and, separately, until turbidity sensors are wired up and `turbidity_init()`/`turbidity_update()` are uncommented in `main.cpp`).

**Why these four sensors weren't closed-loop inputs before now:** `docs/EMBO_UAS_CV_Technical_Advisory.txt` (and this project's own earlier rules) held UAS/turbidity/force to "diagnostic-only until an empirical correlation check proves it" — and until the 9-syringe bench dataset existed, nobody had that proof. Collecting that dataset is what changes them from diagnostic to trustworthy; see `calib_estimate_particle_size_um()` in `calibration.cpp`, which independently checks each channel's calibration curve for monotonicity and excludes any channel that doesn't pass, rather than blindly trusting whatever's plugged in.

**Why no PID even with a live signal now available:** the breakage process is still monotonic and irreversible (mixing only breaks particles smaller, never larger) — overshoot is a ruined batch, not "error to correct from the other side." That rules out a PID regardless of how good the measurement is. Instead, the scheduler strokes at a fixed rate and stops once the fused estimate reads within tolerance for several consecutive checks in a row (debounced against noise) — a hysteresis-style stop condition, not a proportional correction. Full rationale in `scheduler.h`'s header comment.

---

## Operational workflow

The UI is a menu tree (`src/ui.cpp`, `src/ui/screens/*`), driven **by the EC11 knob** (rotate to move a selection or adjust a value, short-press to select/confirm, long-press for a context action) **and BTN1** (Back on menu screens, stop/e-stop on the running screen — see "BTN1's second job" below). Every screen also has touch (XPT2046) handlers for Back/Toggle/Pause/Stop, but **touch is currently non-functional on real hardware** — the SPI bus was reverted to write-only (no MISO) after a boot hang (see "SPI bus" below), so `LGFX::getTouch()` always returns false and `ui_input_poll_touch_tap()` never fires a tap, no matter how complete the per-screen touch code looks. No screen is a dead end because of this: the encoder/BTN1 path covers every navigation action on its own, which is exactly why touch being dark right now isn't currently blocking anything.

Live sensor data stays a BLE-only, diagnostics-only concern for the mixing loop itself (`FORCE ON`/`TURB ON`/`UAS ON`/`FIT`, see below) — the one on-screen exception is the Telemetry screen (Settings > Developer mode > Telemetry), which shows a live readout (load cell, turbidity, UAS, motor position) directly on the TFT.

**Screen tree, as actually wired in `ui.cpp`:**

```
Insert syringe (boot placeholder)
 └─ Start Menu
     ├─ Start ──► Agent Selection (Gelfoam/Lyostypt)
     │             └─► Syringe Type (Terumo/Nipro)
     │                   └─► Target Type (Size/Viscosity)
     │                         └─► Mixing Menu ──► Warning (mount check) ──► Mixing Running ──► End ──► (back to Start Menu)
     │
     ├─ Settings
     │   ├─ Sound toggle
     │   ├─ Motion ──┬─ Home Motors
     │   │            ├─ Move Left Motor (discrete 10-step nudge)
     │   │            ├─ Move Right Motor (discrete 10-step nudge)
     │   │            └─ Stroke Testing (see "Stroke test" below)
     │   └─ Developer mode ──┬─ Telemetry (live on-screen sensor readout)
     │                        └─ UAS Debug Mode (BLE on/off toggle)
     │
     └─ Camera feature ──► mount-check prompt ──► (stub — "feature idea developing in progress")
```

Any screen can reach **VerifyingScreen** (RPi camera capture, `rpi_request_capture()`) via encoder long-press from the Mixing Menu, Warning, or End screens.

Agent (Gelfoam/Lyostypt), Syringe Type, and Target Type (`src/mixing_options.cpp`) are **session-only labels with no calibration effect** — confirmed nothing in `calibration.cpp`/`calibration.h` reads them, and no viscosity-based calibration path exists anywhere in the codebase; Target Type = Viscosity is UI-selectable but not functionally different from Size today.

**Two screen source files exist but are dead code — not reachable from `ui.cpp`'s actual graph above:** `src/ui/screens/developer_mode_screen.*` (an older, self-contained Developer Mode screen with its own inline telemetry — superseded by the plain menu + separate `TelemetryScreen` shown in the tree above) and `src/ui/screens/jog_motor_screen.*` (a continuous encoder-jog screen — superseded by the inline discrete 10-step nudge used by Move Left/Right Motor). Neither is instantiated anywhere; leave them if you're grepping for behavior that doesn't match what you see on the board, or delete them in a future cleanup pass.

**A bench-only back door exists outside this tree:** `ui_open_bench_diagnostics_menu()` (recalibrate UAS baseline, reset the breakage-model fit) is pushed on top of whatever screen is showing, but only in response to the BLE `MENU` command — it's not reachable from any on-screen menu item.

| Stage | Trigger | What happens | Hardware involved |
|---|---|---|---|
| **1. Boot / self-test** | Power on | TMC2209 UART init + SpreadCycle write/readback, AD9833 + UAS baseline sample, HX711 init + fresh tare, then straight to the "Insert syringe" placeholder screen — **no homing happens automatically at boot, and BLE is off by default**. Turbidity init/update are currently commented out in `main.cpp` (sensors not physically connected on the bench) — see "What this firmware does" above. Any `BLOCKING` check failing (see `FIRMWARE_TODO.md`) should halt — no silent bad-data path into the scheduler. | Both TMC2209 modules, AD9833, HX711 x2, status LED |
| **2. Homing** | **Press EC11 knob** on the Mixing Menu while it reads "NOT HOMED" (or the BLE `HOME` command) | `motors_home()` drives both motors to their limit switches and backs off; stroke counter resets to 0. Blocking for the duration of the attempt (same tradeoff already accepted for BLE `HOME`) — nothing can be running yet, since a run itself requires being homed first. On failure, `ui_show_error()` puts the TFT into a persistent fault screen — no way to start a run until the board is rebooted and the fault investigated. The `embo_bench` build (see "Bench testing" below) fakes this step instantly instead and shows a loud on-screen banner so it's never mistaken for a real homed board. | M1/M2 steppers, limit switches (J6/J7), TFT |
| **3. Setup flow** | Start Menu > Start | Agent Selection → Syringe Type → Target Type (all session-only labels, see above) → Mixing Menu, where the encoder adjusts target size (5µm steps, 50–1000µm). | TFT, EC11 |
| **3b. Optional: verify current size** | **Hold EC11 knob** (Mixing Menu, Warning, or End screen) | Requests one RPi capture+CV pass (`rpi_request_capture()`) and shows the median/IQR result on-screen once it replies, color-coded IN SPEC / OUT OF SPEC against the target — an independent double-check, not something that runs automatically, and unrelated to the separate (stub) "Camera feature" menu item. See §"Camera verification" below. | EC11 push-switch, RPi camera, TFT |
| **4. Warning / mount check** | Encoder press on Mixing Menu (once homed) | "Ensure syringe is properly mounted inside" — confirm (encoder press) starts the run; Back (BTN1 short press; the screen's touch Back handler exists but is currently dark, see touch note above) returns to the Mixing Menu without starting anything. | TFT, EC11, BTN1 |
| **5. Running** | Encoder confirm on the Warning screen | Closed loop: the scheduler strokes continuously, and after every stroke reads UAS + force (+ turbidity once re-enabled), converts each through its own 9-point calibration curve, and fuses the trustworthy ones (median) into one size estimate — see `calibration.h`'s `calib_estimate_particle_size_um()`. The screen has a touch **Pause** (holds the run mid-stroke, resumable via `scheduler_pause()`/`scheduler_resume()`) and touch **Stop** (calls the same `scheduler_stop()` as BTN1's short-press) — both currently unreachable with touch dark; **BTN1 short-press (Stop) and long-press (e-stop) are the only ways to affect a running mix today, there is no pause without touch.** | Both motors, UAS chain, HX711 x2, TMC2209 UART, TFT |
| **6. Stop** | **BTN1 short press** (touch Stop exists in code, currently non-functional) | Graceful stop — finishes the in-progress stroke, then holds. | BTN1, both motors |
| **6b. Emergency stop** | **BTN1 held ≥800ms — the ONLY e-stop path.** | Immediate — kills motor power mid-step (`scheduler_emergency_stop()`). **The automatic HX711 over-force e-stop has been removed**: `force_sensor_estop_tripped()`/`HX711_ESTOP_GRAMS` (`calibration.h`) still exist and are still correct as *code*, but `main.cpp`'s `loop()` no longer calls the tripped-check, by deliberate decision — see the comment there. Force readings still feed sensor fusion; they no longer trigger an automatic stop. There is currently **no automatic overforce/jam protection** — a manual BTN1 hold is required. Flag this to whoever owns the safety case before relying on it clinically; see `CALIBRATION.md` §4/§8 for the (currently inert) threshold. | BTN1, both motors |
| **7. Target reached / End screen** | Automatic | The fused sensor estimate reads within `TARGET_TOLERANCE_UM` of the target for `FUSION_CONSECUTIVE_CHECKS_REQUIRED` consecutive stroke-checks in a row (debounced against a single noisy reading), and the scheduler stops itself. If the fusion never converges, a hard `MIXING_MAX_STROKES_SAFETY_CAP` stops the run anyway and flags it as a safety-cap stop, not a confirmed one (`scheduler_hit_safety_cap()`) — a sign to check calibration, not a normal completion. **With turbidity disabled and `SENSOR_CAL_TABLE` unpopulated (see "What this firmware does"), every run currently ends via the safety cap, not a confirmed fusion stop, until both are addressed.** Either way, press-and-hold the encoder knob on the End screen independently confirms the achieved size with a camera capture; BTN1 short-press returns to the Start Menu (the screen's touch "Back to menu" is currently non-functional, same as elsewhere). | TFT |

**Stroke test** (Settings > Motion > Stroke Testing, `stroke_test_screen.cpp`): a bench diagnostic, unrelated to the mixing scheduler's own stroke counter. Drives M1 alone, then M1+M2 concurrently, using its own speed/count/stall-threshold constants (`MOTOR_STROKE_TEST_HZ`, `STROKE_TEST_COUNT_MIN/MAX/DEFAULT`, `STROKE_TEST_STALL_SG_THRESHOLD` — the last is currently 0/disabled, see `config.h`) — for checking mechanical health, not for producing a mixed batch.

**Button/encoder/touch summary** (see `include/config.h` and `src/ui.cpp`):

| Control | Function |
|---|---|
| EC11 rotary | Adjust target particle size (50–1000µm) on the Mixing Menu; move the selection on menu/list screens |
| EC11 push-switch (short press) | Context-dependent: home (if not yet homed) or continue to Warning (Mixing Menu); confirm and start (Warning); select a menu item; toggle (UAS debug mode, sound) |
| EC11 push-switch (held ≥800ms) | Request an optional camera size verification (Mixing Menu, Warning, or End screen) |
| Touchscreen (XPT2046) | Secondary/supplementary — Back, Pause/Stop on the running screen, toggle taps — see individual screens; not required for any navigation path |
| BTN1 (short press) | **Two roles, on mutually exclusive screens** — see "BTN1's second job" below |
| BTN1 (held ≥800ms) | Emergency stop — **only does anything on the Mixing Running screen**; the only e-stop path in this firmware (see 6b above); a no-op everywhere else |

### BTN1's second job

BTN1 was previously overloaded (v2.4/v2.5 firmware used it for start, and a second button for stop), then simplified to exactly one job (stop/e-stop) once the encoder's own switch took over start/confirm — a safety-critical button is easier to trust with one unambiguous function. That principle is preserved, not abandoned: BTN1's short press is now **Back** on every non-running menu/screen, and **remains exactly graceful-stop** on the Mixing Running screen — never both at once, because those are different screens and only one is ever active. Every screen that grants BTN1 the Back behavior gates it behind `!scheduler_is_running()` in code (not just "this screen happens not to be reachable during a run" — see `menu_screen.cpp`'s comment for the reasoning), so even if a future change ever made a menu screen reachable mid-run, BTN1 still couldn't be mistaken for "back" instead of "stop" there. `mixing_running_screen.cpp` itself is untouched by this — its BTN1 handling is exactly what it was before.

The new touch Pause/Stop buttons on the running screen are additional ways to reach `scheduler_pause()`/`scheduler_stop()`, not replacements for BTN1's existing stop/e-stop role there.

### Developer Mode / BLE

BLE is **off by default** — `ble_debug_init()` sets up the NimBLE stack but does not advertise. Turn it on from Start Menu > Settings > Developer mode > UAS Debug Mode (shown on-screen: "turning this mode on will enable Bluetooth"); the same screen shows the current on/off state and lets you toggle it back off. The sibling **Telemetry** screen (Settings > Developer mode > Telemetry, `telemetry_screen.cpp`) shows a live readout (load cells, turbidity, UAS reading, motor position) directly on the TFT — the only screen in this design where raw sensor values are shown on-device rather than BLE-only. (An older, self-contained `developer_mode_screen.cpp` also exists in the source tree with similar inline telemetry, but it's dead code — not reached from `ui.cpp`'s actual menu wiring, see the screen-tree section above.)

### Camera verification (optional, on-demand — independent of the fusion loop)

CV is **never a fusion input** (see above) — it's an **operator-triggered, single-shot check** the doctor can run any time from the Mixing Menu, Warning, or End screen (encoder long-press), to independently confirm what the four onboard sensors already decided. This is unrelated to the Start Menu's separate "Camera feature" item, which is a stub per the current UX design (not yet developed):

1. ESP32 sends `CAPTURE` to the RPi over UART (`rpi_request_capture()`).
2. RPi captures one frame, runs CV once, and replies with `SIZE <median_um> <iqr_um>`.
3. ESP32 displays the result on the TFT (color-coded IN SPEC / OUT OF SPEC against the target) and feeds it into the diagnostic-only breakage-model fit (`calib_breakage_add_point()`) for cross-checking against the fusion estimate in future runs. It does not affect a run already finished or in progress, and it never overrides the fusion-based stop decision.
4. If the RPi doesn't reply within `RPI_CAPTURE_TIMEOUT_MS` (8s, `config.h`), the screen shows a timeout notice instead of hanging indefinitely.

**Future work, not yet implemented:** the RPi may eventually also send a compressed JPEG of the annotated frame (particle circles overlaid) alongside the `SIZE` line, for display on a future UI revision. No wire protocol for that exists yet — see `rpi_uart.h`'s closing comment. This firmware only handles the text `SIZE` reply today.

---

## Flashing via VS Code + PlatformIO

### 1. Install PlatformIO

If you don't have it: open VS Code → Extensions (`Ctrl+Shift+X`) → search **PlatformIO IDE** → Install. Restart VS Code.

### 2. Open the project

Open the folder `firmware/esp32/` in VS Code (not the repo root — PlatformIO needs to see `platformio.ini` at the top level of the opened folder).

```
File → Open Folder → .../EMBO/firmware/esp32
```

PlatformIO will automatically detect the project and download the ESP32-S3 toolchain and all libraries on first open. This takes a few minutes.

### 3. Connect the board

Plug USB-C into **J13** on the EMBO board (the USB-C programming connector). The ESP32-S3 has a native USB CDC/JTAG controller on GPIO19/20 — no USB-UART bridge chip is needed.

Windows should enumerate a COM port automatically. If it doesn't, install the [ESP32-S3 CDC driver](https://docs.espressif.com/projects/esp-idf/en/latest/esp32s3/get-started/establish-serial-connection.html).

### 4. Build

Open the VS Code terminal (`Ctrl+`` `):

```bash
pio run
```

Or click the **checkmark (✓) Build** button in the PlatformIO toolbar at the bottom of VS Code.

### 5. Flash

```bash
pio run --target upload
```

Or click the **right-arrow (→) Upload** button in the PlatformIO toolbar.

PlatformIO auto-resets the ESP32-S3 into bootloader mode via USB CDC control signals. You don't need to press any buttons for a normal flash.

### 6. Monitor serial output

```bash
pio device monitor
```

Or click the **plug Monitor** button. Baud rate is set to 115200 in `platformio.ini`.

For wireless debug output during a run, connect a BLE terminal app (e.g. **nRF Toolbox** or **Serial Bluetooth Terminal**) to the device named `EMBO-Debug` and subscribe to the Nordic UART TX characteristic.

### Bench testing with no motors/limit switches connected

Homing is never automatic at boot in either build — `setup()` always goes straight to the UI (see "Operational workflow" above), and homing only happens when the operator presses the knob on the Mixing Menu (or sends the BLE `HOME` command). With `[env:embo]` (the real env) and no limit switches connected, that homing attempt will time out after `HOMING_TIMEOUT_MS` (30s) and show a HARDWARE FAULT screen — expected, not a bug.

If you want the knob-press homing attempt to succeed instantly with nothing connected (e.g. to get past "NOT HOMED" and exercise the rest of the UI/BLE console), there's a separate bench-only environment that skips the real limit-switch wait:

```bash
pio run -e embo_bench -t upload
```

This is a genuinely different build (`BENCH_NO_HOMING`, see `motors.cpp`), not a runtime flag — **never flash it to a board that has real hardware attached or that a patient/operator might use.** The only on-hardware sign it's running is a red "BENCH BUILD - NO HOMING" banner across the top of the Mixing Menu (plus a loud BLE/serial log line once you press the knob to home) — if you ever see that banner, a "homed" board hasn't actually checked anything, and starting a "run" will drive the motors with no homed reference position. Re-flash the normal `embo` env before any real use.

---

## BLE debug commands

**BLE is off by default** (see "Developer Mode / BLE" above) — turn it on from Start Menu > Settings > Developer mode > UAS debug mode before trying to connect. Once enabled, connect to `EMBO-Debug` over BLE and write commands to the Nordic UART RX characteristic. Responses appear on the TX characteristic (the same stream as `ble_log()` output).

**This is the one place raw sensor data can be pulled off the board** — the TFT deliberately doesn't show it (see Operational Workflow above), so calibration data collection (`../CALIBRATION.md`) happens through this link, not the screen.

Note: this is a separate BLE service (`EMBO-Debug`, Nordic UART Service) from `testing/PCB_Test_Firmware_v3_4`'s dashboard (`EMBO-PCB-Test-v3.4`, custom GATT + a Web Bluetooth page with live charts). That project is a bench-bring-up tool for an unpopulated/newly-assembled board; this one is the production firmware's diagnostic link. Don't expect the web dashboard to work against this firmware or vice versa.

**Recommended app:** Serial Bluetooth Terminal (Android) or nRF Toolbox (iOS/Android). Select the NUS service, subscribe to TX, and use the input bar to send commands.
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

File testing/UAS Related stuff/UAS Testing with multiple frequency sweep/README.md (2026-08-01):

# UAS Testing with multiple frequency sweep

Standalone fork of `testing/PCB_Test_Firmware_v3_4`, isolated into its own
project folder so this work can't interfere with the original bring-up rig.
Adds **runtime frequency control** for the AD9833 driving the UAS
transducer, which the parent project fixes to a single 1MHz tone.

## What's different from `PCB_Test_Firmware_v3_4`

- **New BLE characteristic, `FREQ_CMD`** (write, float32 LE Hz) —
  `src/ble/ble_service.h/.cpp` — applies a new AD9833 drive frequency
  immediately via `uasSetFrequency()` (`src/hal/uas_sensor.h/.cpp`).
- **`TelemetryPacket` gains a `uasFreqHz` field** (right after `uasVolts`)
  so the dashboard always knows which frequency a given voltage reading was
  taken at.
- **Distinct BLE identity** — advertises as `EMBO-UAS-Sweep` with its own
  UUID base (`8f6a2xxx...`), so it can never cross-connect with the parent
  rig's dashboard if both boards are somehow powered nearby.
- Everything else (motors, load cells, turbidity, homing) is carried over
  unchanged from the parent project, for reference/bring-up only — this
  rig's actual purpose is the UAS frequency sweep.

## Dashboard

Open `web/index_logging to record UAS csv data.html` in Chrome or Edge
(Web Bluetooth required) while the board is powered and advertising.

- **UAS Acoustic Chain** card shows live envelope voltage + current drive
  frequency.
- **Manual Frequency Set** card sets one frequency at a time.
- **Automated Frequency Sweep** card: enter start/end/step (Hz) and a
  dwell time per step (ms), click **Run Sweep** — it walks the range,
  settles, and averages the envelope reading at each step, then lets you
  download a `freq_hz, mean_uas_volts, std_uas_volts, n_samples` CSV.
- **Start Recording / Download CSV** (top bar) continuously logs every raw
  telemetry packet (now including `uas_freq_hz`) regardless of whether a
  sweep is running — same as the parent rig's logging page.

All other sensor cards (load cells, turbidity, motors/StallGuard) behave
identically to the parent project.

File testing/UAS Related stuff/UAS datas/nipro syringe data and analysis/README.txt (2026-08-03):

OSCILLOSCOPE VS. PCB CROSS-CHECK -- STROKE 40, 26x GAIN
=========================================================================

PURPOSE
-------
Verify that the PCB's ADC reading at stroke 40 is explained by the actual
raw receive signal (measured independently on the oscilloscope) passing
through the board's known RX amplifier gain -- i.e., confirm the two
measurement methods agree once amplifier saturation is accounted for.

Checked at THREE frequency points instead of one, so the conclusion
doesn't rest on a single reading.

METHOD NOTE: the oscilloscope value used below is the raw peak-to-peak
reading straight off channel 3 (max - min of the captured waveform) --
NOT an FFT-extracted amplitude. This matches how the reading was
actually taken on the bench.

DATA SOURCE
-----------
26 gain/cross check with oscilloscope at 40th stroke/ (TX side.csv, RX side.csv)
26 gain/40th stroke/uas_averaged_summary_*.csv

CALCULATION USED AT EVERY POINT
--------------------------------
    RX amplitude          = RX Vpp / 2
    predicted PCB voltage = baseline + gain x RX amplitude

  where baseline = 1.4498 V (off-resonance level, this stroke's sweep)
        gain     = 26x

=========================================================================
POINT 1 -- 1.00 MHz (peak)
=========================================================================
  TX Vpp (raw max-min)        2.0101 V
  RX Vpp (raw max-min)        0.2109 V
  RX amplitude (Vpp / 2)      105.46 mV

  predicted = 1.4498 + 26 x 0.10546 = 4.1919 V
  ADC/amplifier ceiling       ~3.1 V   <-- predicted EXCEEDS this

  Actual PCB reading @ 1.00MHz, stroke 40:        3.1399 V
  Sweep peak (whole curve, stroke 40):            3.1420 V @ 1.02MHz

  RESULT: predicted (4.19V) exceeds the ceiling, so hard clipping is
  expected. Actual reading (3.14V) sits right at the clipped ceiling,
  not at the linear prediction. MATCH (clipping confirmed).

=========================================================================
POINT 2 -- 0.96 MHz (near-peak flank)
=========================================================================
  TX Vpp (raw max-min)        [ fill in from scope ]
  RX Vpp (raw max-min)        [ fill in from scope ]
  RX amplitude (Vpp / 2)      [ = RX Vpp / 2 ]

  predicted = 1.4498 + 26 x [RX amplitude] = [ calculate once filled in ]

  Actual PCB reading @ 0.96MHz, stroke 40:        3.0350 V
  (already close to the ~3.05V clipping-warning threshold at this
  stroke count -- worth checking whether predicted also exceeds ~3.1V)

  RESULT: [ pending oscilloscope RX/TX capture at 0.96MHz ]

=========================================================================
POINT 3 -- 0.89 MHz (safe flank)
=========================================================================
  TX Vpp (raw max-min)        [ fill in from scope ]
  RX Vpp (raw max-min)        [ fill in from scope ]
  RX amplitude (Vpp / 2)      [ = RX Vpp / 2 ]

  predicted = 1.4498 + 26 x [RX amplitude] = [ calculate once filled in ]

  Actual PCB reading @ 0.89MHz, stroke 40:        1.9133 V
  (well clear of the ADC ceiling -- this is the frequency expected to
  still be in the amplifier's clean, linear operating region)

  RESULT: [ pending oscilloscope RX/TX capture at 0.89MHz ]

=========================================================================
HOW TO COMPLETE POINTS 2 AND 3
=========================================================================
For each frequency (0.96MHz and 0.89MHz), set the AD9833 to that
frequency, capture channel 3 (RX side) on the scope, and read the
peak-to-peak voltage directly off the display (or save the waveform
CSV, same as "RX side.csv"). Report just the Vpp number (in mV or V)
for each, and this file can be filled in and the match/mismatch
verdict completed the same way as Point 1.

=========================================================================
OVERALL VERDICT (so far)
=========================================================================
Point 1 (1.00MHz) confirms the measurement chain model: the oscilloscope
independently shows the amplifier is being driven well past what the
3.1V ADC ceiling can represent, and the PCB's actual reading lands
exactly at that ceiling rather than at the (impossible) linear
prediction. This is strong evidence the PCB and oscilloscope are
measuring the same real signal consistently -- the PCB just can't
display values above its ceiling.

Points 2 and 3 will show whether this same match holds at frequencies
where the PCB is NOT yet clipping (0.89MHz) and right at the edge of
clipping (0.96MHz) -- confirming the model isn't just "everything
reads the ceiling," but genuinely tracks the real signal amplitude
below that ceiling too.

IMPLICATION SO FAR: at stroke 40, the 1.0MHz peak remains unusable
under 26x gain, as expected. Flank frequencies (0.89MHz, 0.96MHz)
should be used instead for any stroke count this high -- consistent
with earlier recommendations in this dataset.

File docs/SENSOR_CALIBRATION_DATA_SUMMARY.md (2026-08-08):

# Sensor Calibration Data Summary (as of 2026-08-08)

Snapshot of every stroke/size/UAS-voltage/load-cell data source found under
`testing/` and `software/Microscope_Imaging_Data/`, organized by agent
(material) and syringe type. This is a **read-only inventory**, not a
calibration table — none of this has been reshaped into
`firmware/esp32/src/calibration.cpp`'s `SENSOR_CAL_TABLE`, which is still
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

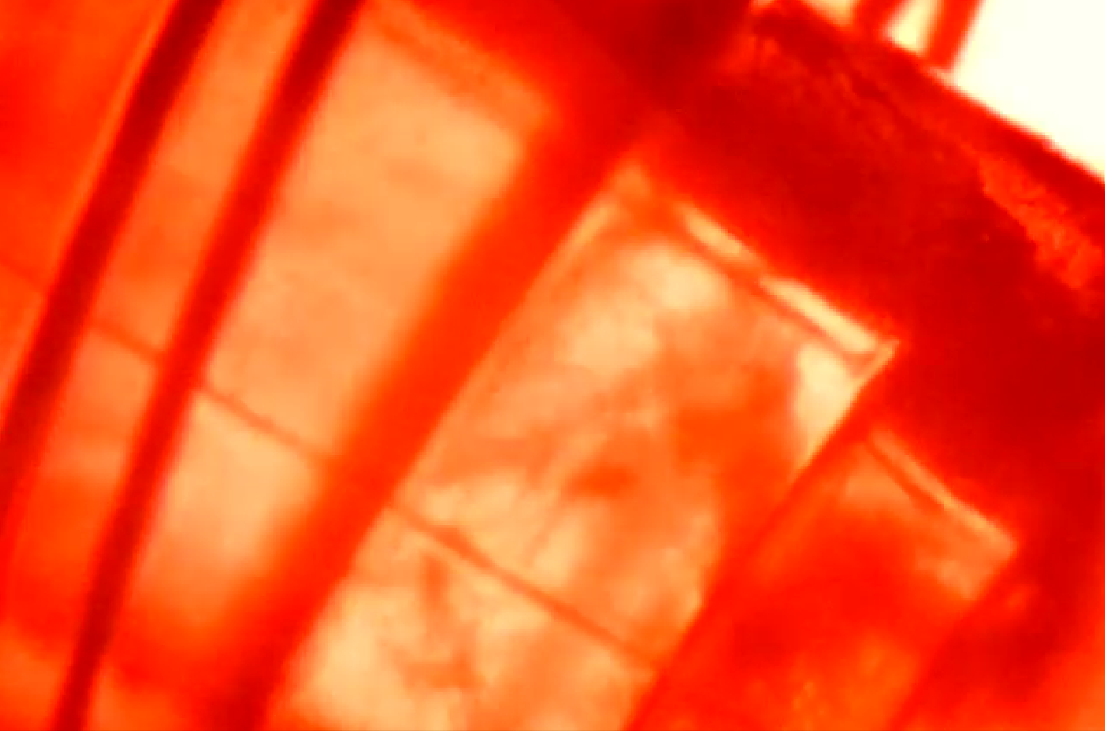
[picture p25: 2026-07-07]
assets/7JUL TEST SCREENSHOT LYOSTYPT.png

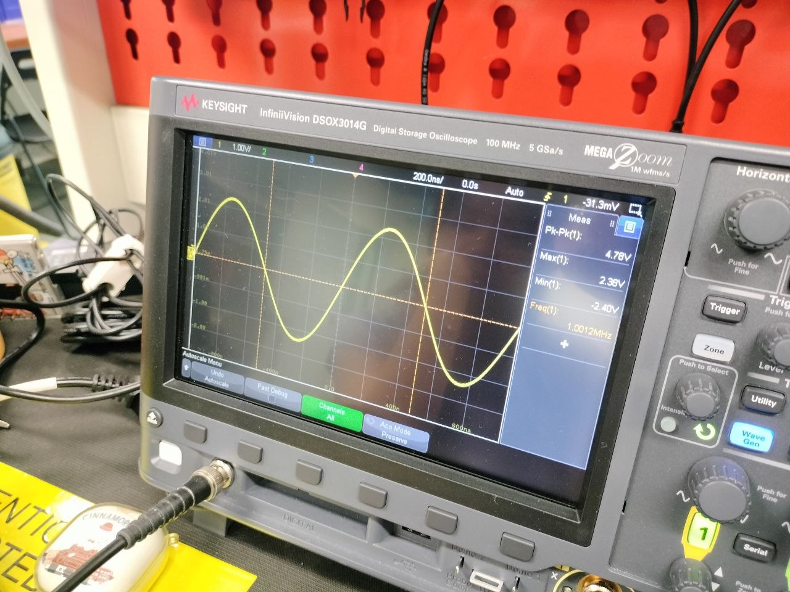
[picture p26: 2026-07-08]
assets/Piezo Prelim Test_Input SIgnal (1MHz Pk-Pk 4.76V).jpg

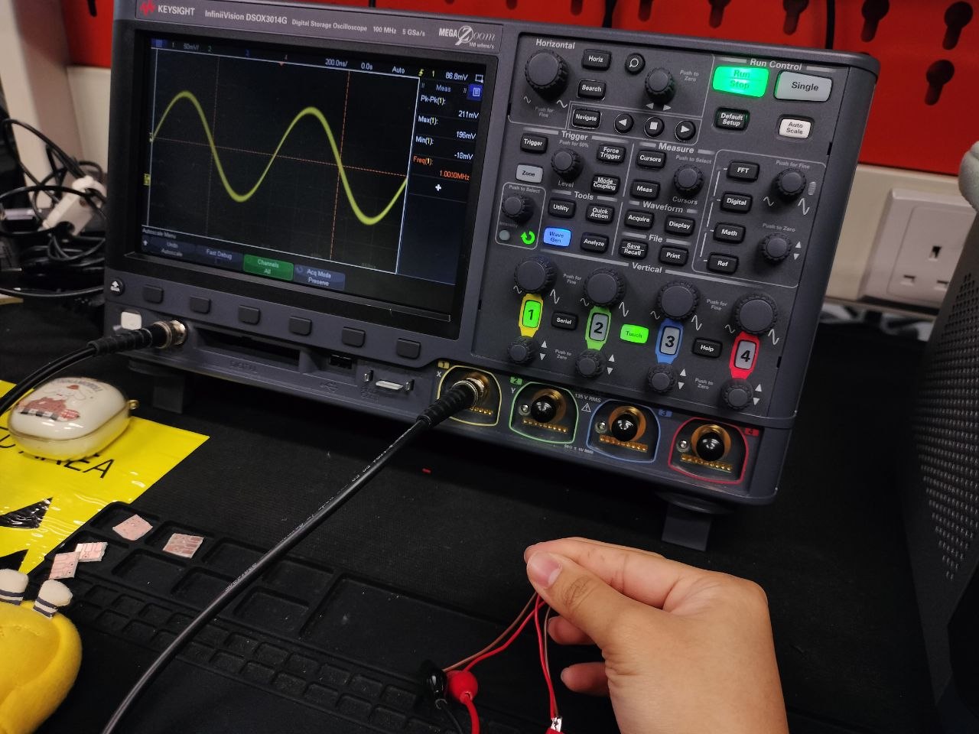
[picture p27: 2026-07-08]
assets/Piezo Prelim Test_Received SIgnal (1MHz Pk-Pk 211mV).jpg

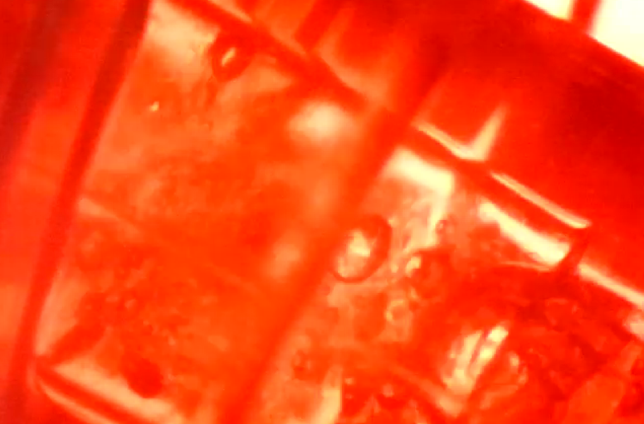
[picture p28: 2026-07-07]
assets/7JUL TEST SCREENSHOT HEMO.png

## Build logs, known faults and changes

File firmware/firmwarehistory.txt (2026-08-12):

Firmware development history

Previously existing functionality
- homing, with edge cases handled 
- testing for strokes 
- main ui framework
- loadcell data logging via serial
- uas data logging via ble and html
- motor limits (in steps)
- working buzzer 

v0.5.1 
- added firmware version numbering in settings ui 
- removed inconsistent "back" buttons in some menus
- included uas tx and rx in serial data collection

v0.5.2 (goal)- to change units from steps into mm, hz into mm/s
- add auto tare after each home for both loadcells
- retained steps due to some math errors, will change units in later version

v0.6.0 (goal) - to a way to take in calibration data and form the motor stopping loop, and add necessary ui elements to that
- added ui elements for menu

v0.6.1
- added calibration equation for uas 

v0.6.2
- change ui colours for main mixing loop
- home before mixing run 
- fixed uas frequency to 0.96MHz

v0.6.3
- fixed ui text bugs
- made ui all readable colours
- fixed homing bugs for main mixing loop
- changed to any button e stop on press during mixing

v0.6.4
- increased stepper current to 700mA for more torque
- homing hz to 2000hz

v0.6.5
- motor stroke speed 8000hz
- stroke test speed to 4000hz
- homing pre nudge to 200steps

v0.6.6 (goal) - acceleration ramp to improve motion, add dynamic speeds to improve torque performance during first few strokes 
- implemented adjustable acceleration ramp to improve motion system
- current is now at 1000mA for torque and speed requirements

v0.6.7 
- fixed random stopping with motion limit fine tuning
- uart check on boot via serial

v0.6.8
- added new menu logic to separate viscosity and particle size 
- added menu logic to grey out irrelevant options based on agent selected

v0.6.9
- add buzzer chirp at end of mixing
- sound mode turn on or off will change whether buzzer will chirp at every button press
- improve the finishing screen
- display uas voltage reading at the end of the run
- changed uas correlation equation

v0.7.0
- ported rpi camera functionality from other code file
- changed main mixing to stop at number of strokes instead of uas (just for the demo)
- increased the detent per encoder rotation to 10um per detent
- increased the max value of selectible particle size

v0.7.1
- remove sound setting totally, add chirp after mixing complete
- remove screen after camera feature

v0.7.2 
- add auto home and push left motor if the camera feature is used
- home pre nudge to 400 steps

v0.7.3
- add loadcell loop equation (right loadcell)
- updated some values in config

v0.7.4 
- fixed mixing loop distinction and screen distinction

v0.7.5
- changed viscosity units to Pas

v0.7.6
- changed back to closed loop particle size uas
- changed the max particle size to 10000um
- stroke testing speed to 10000hz

v0.8.0 (goal) - auto detect syringe inside using uas

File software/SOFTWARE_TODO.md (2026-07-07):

# EMBO CV Pipeline Build-Up TODO

Generated from: `software/cv-pipeline/README.md`, `docs/EMBO_UAS_CV_Technical_Advisory.txt` (July 2026), the firmware UART protocol (`firmware/esp32/src/rpi_uart.cpp`), and the particle-size kinetics model in `docs/EMBO_Project_Overview.md`.

Scope: the Raspberry Pi computer-vision pipeline only. TFT touchscreen UI tasks live in `firmware/FIRMWARE_TODO.md` (tasks 7–10) since that code runs on the ESP32, not the Pi.

Code scaffolding exists (`config.py`, `capture.py`, `uart_link.py`, `detection.py`, `sizing.py`, `main.py`) — Layer 1 (camera + UART) is written but **not yet run on real hardware**, so its checkboxes track implementation, not verification. Layers 2–3 (`detection.py`/`sizing.py`) are deliberately unimplemented stubs that raise `NotImplementedError` rather than fake logic — see the module docstrings.

---

## Layer 1 — Camera + UART bring-up

> Nothing else works until these are done.

### 1. Camera capture `capture.py` ⚠️ written, unverified
- [x] `Camera` class wraps `cv2.VideoCapture`/`v4l2` (not `picamera2`/`libcamera` — camera changed to an off-the-shelf USB 2.0 UVC microscope camera, no CSI involved)
- [x] Frame size/FPS and manual-exposure/autofocus-off requested via `cv2.VideoCapture.set()` — driver support for these varies a lot per UVC camera and is **not yet confirmed to take effect** on the real hardware
- [ ] Check the camera's actual supported resolution/fps combinations (`v4l2-ctl --list-formats-ext`) — USB 2.0 bandwidth (~35–40MB/s effective) caps what's deliverable; don't assume `config.py`'s `FRAME_WIDTH`/`FRAME_HEIGHT`/`CAMERA_FPS` defaults (1280×720@30) are actually achievable until checked
- [ ] Verify stable frame capture at a fixed resolution/exposure with the LED backlight panel powered (confirm the 5V/J8 rail is live — the panel is powered from the main PCB, not GPIO-controlled from the Pi)
- [ ] Confirm focus/working distance on the actual mechanical mount — microscope cameras typically have a short fixed working distance, so the mount planned for the CSI camera may not fit
- [ ] **GATE:** don't judge "camera working" using particle visibility — current backlighting makes hydrated gelatin nearly invisible (see Layer 2). Use an opaque test target or air bubbles to confirm optical alignment first; revisit particle visibility only after Layer 2.

### 2. UART link to ESP32 `uart_link.py` ⚠️ written, unverified
- [x] `FirmwareLink` opens the serial port at 921600 baud via `pyserial`, with `send_size(median_um, iqr_um)` writing `"SIZE <median_um> <iqr_um>\n"` and `send_status(message)` for free-form diagnostics — matches firmware's `sscanf(_buf, "SIZE %d %d")` parser exactly (positive median, non-negative IQR enforced client-side too, raising `ValueError` before a bad packet is even sent)
- [ ] Confirm `config.UART_PORT` (`/dev/serial0`) actually maps to RPi GPIO14/15 on the **Raspberry Pi 5** specifically — Pi 5 uses the RP1 I/O chip, whose UART mapping differs from earlier Pi models this default may have been copied from
- [ ] **Integration test:** confirm via the firmware's BLE log (`"RPi: median=X iqr=Y um"`), not a local print statement — that's the only proof the packet actually parsed correctly on the other end
- [ ] Confirm arbitrary status/error strings sent from the RPi (e.g. `"CAM: init OK"`, `main.py`'s `"CV: detection/sizing not implemented yet"`) are safely ignored by firmware rather than causing a parse error — firmware is designed to discard unmatched lines silently, so this should already be safe, but verify it in practice

---

## Layer 2 — Optical contrast setup

> Per the July 2026 advisory §2 Problem A: hydrated gelatin/collagen is ~80–99% water and near index-matched to saline, so plain backlighting shows bubbles and glare, not particles. Test the cheapest fix first.

### 3. Dye contrast test — highest priority, no hardware change
- [ ] Add visible dye (methylene blue or similar) to the saline; re-run capture; confirm particle contrast visibly improves over plain backlight
- [ ] Save before/after image pairs as the baseline evidence
- [ ] Note dye concentration used, and flag if the dye visibly affects particle buoyancy/behavior during mixing
- [ ] **Test combined with the red-filtered LED backlight** (see below) rather than treating them as alternatives — 7 July test found red filtering helps bubble/particle separation, which is a different effect from dye's particle/saline contrast boost; the two may be complementary

### 3b. Red-filtered LED backlight — confirmed by test (7 July 2026), not yet in the advisory
- [x] **CONFIRMED BY TEST** — red filter on the LED backlight makes bubble outlines less sharp/prominent relative to plain white light, improving particle-vs-bubble discrimination. See `testing/7JUL_stabilised_mixing_video_testing/2026-07-07_stabilised_mixing_video_testing.md`.
- [ ] **Not yet confirmed:** whether the red filter also helps the core particle-vs-saline contrast problem (advisory §2 Problem A), or only bubble suppression — these are two different effects and shouldn't be conflated. Needs a direct side-by-side comparison against plain light and against the dye test.
- [ ] If confirmed as genuinely complementary to dye, add to the standard test lighting configuration rather than treating as a one-off

### 4. Dark-field illumination trial
- [ ] Angle the LED panel obliquely instead of straight backlight (mechanical adjustment — coordinate with the mechanical team on panel mounting)
- [ ] Confirm this suppresses the bulk-transmission near-invisibility problem; test combined with dye, not as a replacement for it

### 5. Cross-polarization trial
- [ ] Add polarizing film to the LED panel + a crossed polarizer on the camera lens
- [ ] Expect glare/bubble-highlight suppression; per the advisory this benefits Lyostypt (birefringent intact collagen) far more than true denatured gelatin sponge, which loses birefringence — treat as a glare-suppression tool for gelatin, not a contrast source
- [ ] Test in combination with dye + dark-field

### 6. Cylindrical-barrel lensing/glare
- [ ] Track separately from the above — this is the same class of fix as the stopcock imaging window in Layer 5 (task 12); don't duplicate effort building two separate optical fixtures

---

## Layer 3 — Detection & sizing model

> Do not resume this layer until Layer 2 confirms particles are actually visible in captured frames — training/tuning a model against near-invisible particles is wasted effort.

### 7. Switch to instance segmentation `detection.py` — stub only
- [x] `ParticleDetector` class scaffolded — `detect()` deliberately raises `NotImplementedError` rather than a fake/placeholder result, so a broken pipeline can't silently look like it works
- [ ] Evaluate YOLOv8-seg vs Cellpose (purpose-built for dense/touching irregular blobs) — bounding boxes cannot resolve overlapping/stacked particles, per-pixel instance masks can (advisory §2 Problem B)
- [ ] Re-annotate training data with segmentation masks, not just bounding boxes — this is a real data-prep cost, budget time for it
- [ ] Retrain using images captured under the finalized Layer 2 optical setup — earlier bounding-box-era training images are not valid once dye/lighting changes the input distribution
- [ ] Implement `ParticleDetector.detect()` for real once the above are done

### 8. Sizing metric — Equivalent Circular Diameter (ECD) `sizing.py` — stub only
- [x] `compute_ecd_stats()` scaffolded with the `SizeStats` return shape — also raises `NotImplementedError` rather than a fake formula, since a wrong sizing calculation would silently poison the firmware PID target check
- [ ] Adopt ECD (diameter of a circle with equal projected area) as the primary size metric per ISO 13322 / ISO 9276-6 — gelatin/collagen fragments are irregular "snowflake"-like, not circular, so a naive diameter isn't well-defined (advisory §2 Problem C)
- [ ] Compute median/IQR over the ECD distribution, replacing any bounding-box-diagonal-based sizing
- [ ] Also compute and log max/min Feret diameter and solidity (area / convex hull area) — secondary signals for "how irregular/branching" the population still is, useful for tracking mixing progress even before they're sent to firmware
- [ ] Calibrate `um_per_pixel` against a known reference (e.g. glass beads of known diameter) — `main.py` currently passes a placeholder `1.0`

---

## Layer 4 — Protocol integration with firmware

### 9. UART packet — ECD median/IQR `uart_link.py`
- [x] Wire format implemented (`FirmwareLink.send_size()`) — sending real ECD-based `median_um`/`iqr_um` is blocked on task 8, not on the transport, which is already done
- [ ] Send ECD-based `median_um`/`iqr_um` using the existing `"SIZE <median_um> <iqr_um>\n"` format — no firmware change needed for this part alone
- [ ] **Coordinate with firmware before adding Feret/solidity fields.** Firmware's `sscanf` parser in `rpi_uart.cpp` silently ignores extra trailing fields rather than erroring — new fields would arrive over UART but never reach firmware logic until `rpi_uart.cpp`/`rpi_uart.h` are explicitly extended (already flagged in `FIRMWARE_TODO.md`). Don't assume sending more data "just works."
- [ ] If extending the protocol, agree an explicit versioning approach with the firmware owner (e.g. a distinct message type) rather than letting the two sides drift out of sync silently

---

## Layer 5 — Validation & materials

### 10. Empirical UAS-vs-CV correlation logging (joint task with firmware)
- [ ] At several stroke counts, simultaneously capture CV-measured true median/IQR and the firmware's BLE `UAS ON` stream (per-frequency attenuation) — see `firmware/FIRMWARE_TODO.md` task 5, which is **BLOCKING** on the firmware side until this is done
- [ ] Sequence this after Layers 2–3 are working — CV output has to be trustworthy before a correlation check against it means anything

### 11. Ground-truth test material sourcing
- [ ] Source verified pharmaceutical-grade absorbable gelatin sponge (e.g. Surgispon) or Chinese-pharmacopoeia-grade 吸收性明胶海绵 for valid ground-truth testing/training material
- [ ] **Do not use Lyostypt as a Gelfoam stand-in** — it's bovine collagen, structurally different, which explains its non-gelling stringy behavior in earlier tests (advisory §3)
- [ ] If using a DIY gelatin foam (freeze-dried foamed gelatin solution, dehydrothermally cross-linked at 100–160°C for 24–72h, no chemical crosslinker) for day-to-day iteration: cross-validate its fragmentation behavior against real purchased sponge before trusting absolute size numbers calibrated on it — cross-link density affects fragmentation kinetics, so DIY and real material may not fragment the same way under identical mixing

### 12. Stopcock optical window + strobed illumination — stretch goal, highest effort
- [x] Overlap avoided — **confirmed by test**, not just theory. Camera repositioned to the stopcock aperture (see `testing/3JUL_stopcock_aperture_testing/`); particles are constrained close enough to a single layer that the barrel-imaging overlap problem (§2 Problem B) is resolved at this imaging site.
- [ ] Scope early if pursuing — requires custom part fabrication (clear stopcock insert or modified bore); coordinate with the mechanical team well ahead of the exhibition deadline
- [x] **CONFIRMED BY TEST (3 July 2026) — motion blur under continuous lighting.** Two continuous-illumination sources tested (smartphone backlight, camera's built-in LED) — both produced significant motion blur from particle flow velocity through the aperture. This is the exact failure mode the advisory predicted for continuous lighting at this imaging site, now observed directly rather than theoretical. See `testing/3JUL_stopcock_aperture_testing/2026-07-03_stopcock_aperture_testing.md`.
- [ ] **No longer deferrable.** Strobed, short-duration illumination synced to the camera trigger is required before this imaging site is usable at all — not an optional refinement layered on top of a working continuous-light setup, since continuous lighting has now been tested and confirmed unusable here.
- [ ] **UPDATE — higher risk now than originally scoped.** The original plan assumed a global-shutter sensor, where strobing mainly compensates for flow velocity. The USB microscope camera now in use is very likely **rolling shutter**, which adds frame skew/distortion on top of blur for anything moving during readout — strobe timing and exposure duration need to be tight enough to freeze motion within a single row-readout window, not just "short enough to avoid blur." Once strobing is implemented, re-test to isolate whether continuous-vs-strobed was the whole problem, or whether rolling-shutter skew is a separate remaining issue.
- [ ] **Go/no-go check first:** verify bubble/cavitation formation risk at the constriction before committing to the full optical build — pressure drop can nucleate bubbles, and this is also the point of maximum shear, so bubble noise may be worse here, not better

---

## Layer 6 — Exhibition readiness

### 13. Model packaging & runtime robustness
- [ ] Package trained weights + inference code for the actual demo Raspberry Pi — weights are gitignored (`weights/`), so confirm the demo unit has the current trained weights, not a stale local copy
- [ ] Handle camera/UART disconnects and bad frames gracefully — keep sending status strings (which firmware safely ignores) rather than crashing the process, matching firmware's assumption that "RPi can send status strings freely"
- [ ] Confirm inference frame rate/latency is fast enough not to starve the ESP32 PID loop of fresh median/IQR updates during a live run

### 14. Live demo rehearsal
- [ ] Full end-to-end run-through on real (or cross-validated DIY) gelatin foam: dye + lighting → segmentation → ECD sizing → UART → firmware PID stop condition
- [ ] Deliberately exercise the edge cases in front of a test audience first — bad frame, UART hiccup, low model confidence — don't let the first occurrence be at the actual exhibition

---

## Verification gates

Complete these checks in order before closing each layer.

| After task | What to verify |
|---|---|
| 1 | Camera captures stable frames; UART link accepted by firmware — BLE log shows `"RPi: median=X iqr=Y um"` |
| 3 | Dye visibly improves particle contrast vs plain backlight in saved before/after images |
| 5 | Dark-field/cross-pol combo suppresses glare/bubble highlights without erasing the dye contrast gained in task 3 |
| 7 | Instance segmentation resolves particles that bounding-box detection merged or missed, on the same test image set |
| 8 | ECD/Feret/solidity outputs are sane on a known reference (e.g. glass beads of known diameter) before trusting them on real gelatin |
| 10 | UAS-vs-CV correlation is either confirmed clean and monotonic (promote UAS beyond diagnostic-only) or confirmed weak (leave it diagnostic-only) — not left undecided |
| 12 | *(if pursued)* No unexpected bubble/cavitation increase at the stopcock constriction, checked before fabricating the optical window |
| 14 | Full end-to-end run completes without manual intervention on real or cross-validated gelatin foam |

---

## Materials & coordination checklist

### Before optical changes
- [ ] Confirm dye choice (methylene blue or alternative) doesn't interfere with downstream chemistry/injection use of the slurry — this is a test rig, but worth a sanity check given the material is nominally a medical embolic agent
- [ ] LED panel angle/mount changes for dark-field trial — coordinate with mechanical team on bracket/mount rework, don't just tape it at an angle for the demo

### Protocol coordination
- [ ] Confirm with firmware owner whether/when `rpi_uart.cpp` gets extended to accept Feret/solidity fields, or whether those stay CV-side-only diagnostics for now
- [ ] Confirm UART baud/pin assignment hasn't changed on a PCB rev before assuming `GPIO47/48` ↔ `GPIO14/15` still applies

### Materials sourcing
- [ ] Surgispon (or equivalent pharma-grade sponge) ordered with enough lead time for both CV training data and mechanical/electrical integration testing
- [ ] DIY gelatin foam recipe (if used) documented with exact cross-link time/temperature per batch, so size calibration drift can be traced back to a specific batch

---

## Notes

- **UART protocol is intentionally minimal.** `"SIZE <median_um> <iqr_um>\n"` is the only format firmware currently parses. Anything else sent by the RPi is silently discarded — useful for free-form status logging, but means new metrics need an explicit protocol decision, not just "send more data."
- **Advisory's own priority order** (given limited time before exhibition, `docs/EMBO_UAS_CV_Technical_Advisory.txt` §4): 1) dye test, 2) empirical UAS-vs-CV correlation check, 3) dark-field/cross-polarization lighting trial, 4) switch to instance segmentation, 5) stopcock optical window + strobed illumination. This TODO's layering follows that same priority, just grouped by build-up dependency rather than a flat list.
- **Don't retrain before Layer 2 is settled.** Every optical change (dye, lighting angle, polarizers) changes what the camera actually sees — training data collected before the optical setup is finalized will need to be recollected, not reused.
- **Cross-reference `firmware/FIRMWARE_TODO.md`** for anything that touches the ESP32 side: UART parsing (task 4), the UAS-vs-CV correlation gate (task 5), and the TFT UI that displays this pipeline's output (tasks 7–10).

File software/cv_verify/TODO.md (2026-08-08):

# CV Verify — TODO (on-demand, out-of-loop CV check, Pi Zero 2W)

This is a **new, separate workspace** — nothing here touches `software/cv-pipeline/`
(that's your friend's Layer-1-through-3 build-up, left as-is). This folder picks up
from the current firmware reality and rebuilds only what changed.

## Why this doc exists

`../SOFTWARE_TODO.md` was written when CV was meant to be a **continuous stream**
feeding the ESP32's control loop, on a **Pi 5**. Neither is true anymore:

- `firmware/esp32/include/rpi_uart.h:5-8` and `FIRMWARE_TODO.md` task 6 — the
  scheduler now closes the loop on four other sensors (UAS + 2× turbidity + force).
  CV is **optional, on-demand, single-shot** — the ESP32 sends `"CAPTURE\n"` and
  expects one `"SIZE <median_um> <iqr_um>\n"` reply, not a repeating stream.
- We're moving to a **Pi Zero 2W**, not a Pi 5. Weaker CPU (quad A53 @ 1GHz vs
  the 5's Cortex-A76), different camera connector, and — usefully — the RP1-chip
  UART-mapping uncertainty flagged in the old TODO (task 2) mostly goes away since
  the Zero 2W behaves like the well-documented Pi 3/4 UART story, not the 5's RP1 I/O chip.

So the old TODO's Layer 1 (continuous capture loop, streaming UART) needs replacing,
not just extending. Layers 2–3 (optical contrast, detection/sizing) are still valid —
those don't care whether the trigger is a loop or a command.

---

## Layer 0 — Pi Zero 2W bring-up

Different from `RPI_SETUP_GUIDE.md` in a few places worth calling out, not just
"same steps, different board":

- [ ] Flash Raspberry Pi OS **Lite** (64-bit) — no desktop needed, and the Zero 2W
  has less headroom than a 5 for a GUI sitting in the background eating RAM (512MB
  total).
- [ ] **Camera connector:** Zero 2W uses the small MIPI CSI connector, not the
  standard one on a Pi 5/4. The Global Shutter Camera's ribbon cable needs a
  Zero-format adapter cable (sold separately) — confirm you have one before wiring
  anything else.
- [ ] **UART:** same fix as the old guide (§7) — `dtoverlay=disable-bt` in
  `/boot/firmware/config.txt` + `sudo systemctl disable hciuart`, so GPIO14/15 gets
  the real PL011 UART instead of the mini-UART shared with Bluetooth. This is the
  standard Pi 3/Zero 2W story (RP1-specific uncertainty in the old task 2 was a
  Pi-5-only problem).
- [ ] Confirm `/dev/serial0` exists and maps to GPIO14/15 after the above + reboot.
- [ ] `sudo usermod -aG video,dialout $USER`, log out/in.

## Layer 1 — Request/reply UART link (replaces old task 2 + main.py loop)

The whole shape of `main.py` changes: no more `while True: capture, try detect,
sleep(0.1)` free-running loop. Instead, **block waiting for a line from the ESP32**,
and only capture+run CV when `"CAPTURE\n"` arrives.

- [ ] New `link.py` in this folder: open `/dev/serial0` at 921600 baud, blocking
  (or short-poll) read for a line, filter for exactly `"CAPTURE"`.
- [ ] On `CAPTURE`: grab one frame, run detection+sizing, send
  `"SIZE <median_um> <iqr_um>\n"` — **must reuse the exact wire format** your
  friend's `uart_link.py` already used (`sscanf(_buf, "SIZE %d %d")` on the
  firmware side is fixed and shared — don't invent a new format here).
- [ ] **Hard budget: `RPI_CAPTURE_TIMEOUT_MS = 8000`** (`firmware/esp32/include/config.h:157`).
  If capture + inference doesn't reply inside 8s, the ESP32 marks it
  `TIMED_OUT` and moves on. This is the one place Pi Zero 2W's weaker CPU is a real
  risk vs a Pi 5 — budget time explicitly:
  - [ ] Measure raw capture time alone first (no model) — establish the floor.
  - [ ] Once a real detection model exists (Layer 3, still blocked on optics),
    measure YOLOv8-seg/Cellpose inference time on the Zero 2W specifically. If it
    blows the 8s budget, options are: a lighter model, lower input resolution, or
    (last resort) asking firmware to raise `RPI_CAPTURE_TIMEOUT_MS` — coordinate
    before changing firmware.
- [ ] While waiting for `CAPTURE`, it's fine (and expected) to send free-form
  `send_status()` lines — firmware silently discards anything that isn't a valid
  `SIZE` line, same guarantee your friend's version relied on.
- [ ] No more periodic streaming — being idle between `CAPTURE` requests is the
  correct resting state, not a bug.

## Layer 2 — Optical contrast setup

**Reprioritized from `../SOFTWARE_TODO.md` tasks 3–6 — dye is off the table.**
Camera confirmed as **OV9281-110** (global shutter mono, no IR-cut filter,
sensitive out to ~900–1000nm) — consistent with the earlier UVC→global-shutter
pivot, and mono doesn't invalidate the red-filter result (see below).

- [ ] **Dye contrast test — REMOVED, not just deprioritized.** This device operates
  on real material in active medical use (embolization slurry); adding a chemical
  contrast agent to the material isn't an option outside a bench-only test rig.
  This was the advisory's #1 recommendation and the only fix that addresses the
  *fundamental* problem (gelatin ~index-matched to saline) — removing it means
  contrast has to come entirely from illumination geometry instead, and results
  may end up weaker than the earlier dye-assisted petri-dish tests. Flag this
  honestly rather than assuming dark-field alone will fully recover what dye gave up.
- [ ] **Dark-field / oblique illumination — now highest priority (was task 4).**
  Angle the LED panel obliquely instead of straight backlight. This is the standard
  technique for imaging transparent phase objects *without* a stain — unscattered
  light misses the lens, light scattered by a particle enters it, so particles
  read bright against a dark background. Unlike red-filtering/plain backlight
  (which assumed dye handled the core contrast problem), this is built for
  exactly the no-dye case. Mechanical coordination needed for the panel mount
  (per old task 4).
- [ ] **Cross-polarization — second priority (was task 5), pair with dark-field,
  not standalone.** Polarizing film on the LED panel + a crossed polarizer on the
  camera lens (you already have a polarizer). Good for suppressing syringe-wall
  glare/specular reflection on top of dark-field; per the advisory it benefits
  birefringent material more than true denatured gelatin, so don't expect it to
  fix bulk transparency alone.
- [ ] **Red-filtered backlight — still valid, refinement layer (was task 3b).**
  7 July result (bubble/particle discrimination improved) is **not invalidated
  by the mono sensor** — the effect came from restricting illumination
  wavelength (less chromatic scatter/glare reaching the lens), not from Bayer
  color separation, so a mono sensor benefits identically.
- [ ] **NIR illumination — stretch/secondary experiment, not priority-1.** OV9281's
  lack of an IR-cut filter means NIR (~850–950nm) illumination is a legitimate
  extra contrast lever — water/saline absorption differs from visible in some NIR
  bands — without adding anything to the slurry. Needs an NIR LED; only worth
  pursuing once dark-field's baseline result is known, not before.
- [ ] **Fallback if dark-field + polarization still isn't enough:** don't keep
  iterating on lighting indefinitely — reconsider the imaging site instead (the
  stopcock aperture work, old task 12, where particles are constrained to a thin
  layer and scatter differently), or accept CV as a lower-confidence verification
  signal. This is survivable specifically because CV is optional/out-of-loop now
  (Layer 4) — a weak verification signal doesn't stall a mixing run the way it
  would have under the old continuous-fusion design.
- [ ] Cylindrical-barrel lensing/glare (old task 6) — still track together with
  the stopcock imaging-window fallback above, not as a separate optical fixture.

This problem doesn't care whether CV is continuous or on-demand — the reprioritization
above is driven by the no-dye constraint and camera choice, not the trigger model.

## Layer 3 — Detection & sizing model

**Unchanged from `../SOFTWARE_TODO.md` tasks 7–8** — same optics-gate, same
segmentation-vs-bounding-box reasoning, same ECD sizing metric. On-demand vs
continuous doesn't change *what* the model needs to do, only *when* it's
invoked and how forgiving the latency budget is (see Layer 1 above — on-demand
is actually more forgiving, since there's no real-time feed to starve).

## Layer 4 — Verification-specific integration

- [ ] Confirm the ESP32-side trigger path works end-to-end: UI encoder long-press
  or BLE `CAPTURE` command → `rpi_request_capture()` → your Pi replies → BLE log
  shows `RPi: median=X iqr=Y um` (`firmware/esp32/src/rpi_uart.cpp:36`) → UI
  verification screen shows the result (`firmware/esp32/src/ui.cpp`, per
  `FIRMWARE_TODO.md` task 7).
- [ ] Log every verification result locally on the Pi too (timestamp, stroke count
  if you can get it over BLE, median/IQR) — useful for the diagnostic breakage-fit
  cross-check firmware already supports (`calib_breakage_add_point()`,
  `FIRMWARE_TODO.md` task 6) and for your own sanity-checking against the 9-syringe
  fusion calibration.
- [ ] This is explicitly **not** a fusion input anymore (`FIRMWARE_TODO.md`
  task 6) — don't build anything here that assumes the ESP32 is waiting on you to
  keep a control loop alive. Worst case for a slow/failed capture is a timeout
  notice on the verification screen, not a stalled mixing run.

## Verification gate

| After | What to verify |
|---|---|
| Layer 0 | `/dev/serial0` exists, camera visible via `libcamera-hello` |
| Layer 1 | Send `CAPTURE` manually from a terminal/BLE, confirm a `SIZE` reply appears within 8s and firmware's BLE log parses it |
| Layer 3 | Once optics + model are ready, a real `CAPTURE` round-trip returns a sane median/IQR on known material |

## Notes

- Don't edit `../cv-pipeline/` — that's your friend's checkpoint of the old
  continuous-loop approach, kept for reference/reuse of `detection.py`/`sizing.py`
  once Layer 2/3 unblock (those two files' logic is orientation-agnostic — loop vs
  on-demand doesn't change what's inside them, so they're worth importing here
  rather than rewriting from scratch once they're implemented).
- `../RPI_SETUP_GUIDE.md` is still ~90% correct for a Zero 2W (SSH, VS Code
  Remote-SSH, venv setup are all identical) — only §7's camera-connector and
  UART-quirk details differ, both called out in Layer 0 above.

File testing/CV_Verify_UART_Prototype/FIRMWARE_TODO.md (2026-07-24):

# EMBO Firmware Build-Up TODO

Generated from: PCB Design Brief v3.4, Pinout Cheatsheet, Project Overview, and firmware stub audit.

See [`../firmware/CALIBRATION.md`](CALIBRATION.md) for the calibration procedure behind every raw-sensor-to-physical-value constant referenced below — this file tracks build-up tasks, that one tracks measurement/tuning values.

---

## Layer 1 — Hardware bring-up

> Nothing else works until these are done.

### 1. TMC2209 UART init + SpreadCycle enforcement `src/motors.cpp` ✅
- [x] Initialize TMCStepper on GPIO4, half-duplex, address 0 (U5) and address 1 (U6)
- [x] Write `GCONF.en_spreadcycle = 1` to both drivers at every boot
- [x] Read back GCONF/DRVSTATUS and assert the write succeeded (hardware verification gate)
- [x] Set `GCONF.I_scale_analog = 0` — disable trimpot current control
- [x] Configure `IHOLD_IRUN` via UART for consistent run-to-run current
- [x] Set `TCOOLTHRS = 0xFFFFF` — enables StallGuard across the full speed range
- [x] *(historical)* `pid.cpp`'s init/seed fixes from the original audit — moot now that `pid.cpp` has been replaced by `scheduler.cpp` (Layer 3, task 6), kept here only as a record of what the old bug was
- [x] Fix: `platformio.ini` corrected from `ST7789_DRIVER` → `ILI9341_DRIVER` *(also moot — display library is now LovyanGFX, not TFT_eSPI, see Layer 4 task 7)*

### 2. LEDC step output channels `src/motors.cpp` ✅
- [x] Configure LEDC ch0 → `PIN_STEP_M1`, ch1 → `PIN_STEP_M2`
- [x] Implement `motor_set_speed()` — set LEDC frequency, 50% duty; pass 0 to stop
- [x] Kill LEDC channel (duty=0) immediately inside limit switch ISRs

### 3. AD9833 DDS init `src/uas.cpp` ✅
- [x] Initialize AD9833 over SPI: GPIO38 CS, Mode 2 — bill2462 library handles mode switching per-transaction
- [x] SPI.begin() called with explicit pins before AD9833.begin() and before the TFT (LovyanGFX) initializes — see the integration note in `uas_init()` about the two now being separate SPI driver paths sharing the same physical bus
- [x] Configure 1MHz sine output on REG0
- [x] Wait 10ms after output enable before sampling baseline (>> 5× RC envelope τ=100µs)
- [x] ADC raw → mV via esp_adc_cal_characterize() + esp_adc_cal_raw_to_voltage()
- [x] HARDWARE NOTE: AD9833 MCLK assumed 25MHz — verify on first bring-up
- [x] **UPDATE (July 2026 technical advisory)** — single-tone 1MHz reading replaced with a 3-point sweep (900kHz/1MHz/1.1MHz, `config.h`) each `uas_update()` cycle. Firmware/timing-only change, no board respin. See `docs/EMBO_UAS_CV_Technical_Advisory.txt` §1.
- [ ] HARDWARE GATE: the ±10% frequency spacing is a placeholder — verify it sits within the real transducer's -3dB bandwidth before trusting the off-center points. Widen/narrow `UAS_FREQ_HZ_0/2` in `config.h` if not.

---

## Layer 2 — Data pipelines

> Unblocks sensing and the RPi link.

### 4. RPi UART protocol parser `src/rpi_uart.cpp` ✅
- [x] Parse incoming `"SIZE <median_um> <iqr_um>\n"` packets via `sscanf`
- [x] CR stripped for robustness against Windows-style line endings from RPi
- [x] Unrecognised lines silently discarded — RPi can send status strings freely
- [x] Each valid packet logged over BLE: `"RPi: median=X iqr=Y um"`
- [x] **CV moved to on-demand, single-shot verification.** `rpi_request_capture()` sends `"CAPTURE\n"`; the RPi is expected to capture one frame, run CV once, and reply with the same `SIZE` line — no longer a continuous stream. `rpi_capture_status()`/`rpi_pop_capture_result()` track pending/ready/timed-out state (`RPI_CAPTURE_TIMEOUT_MS`, `config.h`). See `ui.cpp`'s verification screen and `ble_debug.cpp`'s `CAPTURE` command.
- [ ] **RPi-side work still needed** (per user direction, not yet built): the RPi must actually implement the `CAPTURE` request/reply side of this protocol (capture-on-demand instead of whatever loop it runs today). Coordinate with `software/cv-pipeline/`.
- [ ] **Future work, deliberately not stubbed out yet:** an annotated JPEG (particle circles overlaid) alongside the `SIZE` reply, for display on a future UI revision. No wire format decided — see the closing comment in `rpi_uart.h`.

### 5. UAS attenuation baseline `src/uas.cpp` ✅
- [x] Baseline sampled automatically at end of uas_init() after AD9833 settle, now per-frequency
- [x] uas_get_baseline_mv(freq_idx) exposed for BLE debug sanity check on first bring-up
- [x] **UPDATE (this revision)** — UAS is now one of FOUR closed-loop sensor-fusion inputs
  (`scheduler.cpp`, task 6), not a diagnostic-only trend signal. It earns that status the
  same way the July 2026 advisory always said it would have to: an empirical correlation
  check, now made concrete as the 9-syringe bench calibration (`SENSOR_CAL_TABLE`,
  `calibration.cpp`) plus an automatic monotonicity gate at runtime
  (`calib_estimate_particle_size_um()`) that excludes this channel if its calibration curve
  isn't actually monotonic, rather than trusting it unconditionally.
- [ ] **BLOCKING before UAS is trusted as a fusion input** — the 9-syringe bench session
  (`CALIBRATION.md` §5) must actually run and populate `SENSOR_CAL_TABLE`'s `uasAttenuation`
  column. Until then this column is all zeros, which the monotonicity check correctly
  refuses to trust (see `FusedSizeEstimate.uasTrusted`) — so UAS is safely excluded from
  fusion by default, not silently wrong.
- [ ] Independently of the fusion gate, still worth running the UAS-vs-CV correlation check
  described previously: connect via BLE, run `UAS ON`, trigger a `CAPTURE` at several
  points in a real run, and log the per-frequency attenuation + that CV result together.
  This is now a cross-check on the fusion result, not the thing that decides whether UAS
  is used at all.
- [ ] HARDWARE GATE: verify attenuation ratio shifts measurably between air and slurry-filled syringe before trusting in anything downstream

---

## Layer 3 — Mixing scheduler + motor integration

> The core control logic. **Closed loop, on four live sensors — NOT on CV.** See below.

### 6. Mixing scheduler `src/scheduler.cpp`, `src/calibration.cpp` ✅ structure in place
- [x] **CV moved to optional, on-demand, single-shot verification** (per project
  direction) — the RPi only captures+runs CV when the ESP32 explicitly asks
  (`rpi_request_capture()`, task 4 above). It is NOT one of the scheduler's fusion inputs.
- [x] **Closed the loop on the OTHER four sensors instead** — UAS attenuation, APDS9960
  turbidity, MAX30102 turbidity, and load-cell force. Each is calibrated against a 9-point
  bench dataset (`SENSOR_CAL_TABLE`, `calibration.cpp` — known particle sizes from 9
  reference syringes) and inverted through its own curve into a size estimate; the
  estimates from channels that pass a monotonicity sanity check are fused (median) via
  `calib_estimate_particle_size_um()`. This directly replaced an earlier, wrong assumption
  (from a prior pass of this task) that removing CV meant going open-loop entirely — it
  didn't; it meant closing the loop on the sensors that were always meant to earn this role
  once real calibration data existed. See `scheduler.h`'s header comment for the full
  history and rationale.
- [x] Replaced the PID loop (`pid.cpp`, deleted) with a stroke-then-check hysteresis
  design, NOT a proportional/integral/derivative controller — the breakage process is
  still monotonic/irreversible (rules out a PID integral term regardless of how good the
  live measurement is). The scheduler strokes continuously and, after every stroke, checks
  the fused estimate; it stops once that estimate reads within `TARGET_TOLERANCE_UM`
  (config.h) of the target for `FUSION_CONSECUTIVE_CHECKS_REQUIRED` consecutive checks in a
  row (calibration.h) — debounced so one noisy reading can't stop an irreversible process
  early.
- [x] `MIXING_MAX_STROKES_SAFETY_CAP` (calibration.h) is a hard backstop: if the fused
  estimate never converges, the run stops anyway at this stroke count and
  `scheduler_hit_safety_cap()` reports true — a sign to check calibration, not a normal
  completion.
- [x] The breakage-kinetics model (`ln(D-D_min) = ln(D0-D_min) - k*N`, `calibration.cpp`)
  is KEPT but demoted to diagnostic-only — it no longer drives anything the scheduler
  does. It's still fed by operator-triggered camera verifications (`calib_breakage_add_point()`)
  and readable via the BLE `FIT` command, purely as a cross-check against the live fused
  estimate. `calib_breakage_reset()` is manual only (BLE `FIT RESET`), for when the
  material genuinely changes.
- [ ] **BLOCKING before this is trustworthy** — `SENSOR_CAL_TABLE` (calibration.cpp) is
  still all placeholder zeros. Every column reads as "not monotonic" against an all-zero
  table, which correctly means `calib_estimate_particle_size_um()` excludes every channel
  and returns `numChannelsUsed = 0` — i.e. the fusion safely refuses to estimate anything
  rather than producing a wrong number, but this also means the scheduler currently has NO
  way to stop except the safety cap. Run the full 9-syringe bench session
  (`CALIBRATION.md` §5, `ble_debug.cpp`'s `FUSION` command) before trusting this on a real
  mixing run.
- [ ] StallGuard remains NOT a fusion input (never validated as a size proxy, per the
  technical advisory) — it's diagnostic-only, same as before.
- [ ] Force sensing (HX711) is BOTH a fusion input AND an independent e-stop safety input
  (`calib_force_estop_tripped()`) — confirm the e-stop threshold work (`CALIBRATION.md`
  §4) is done separately from the fusion calibration; they're independent thresholds that
  happen to share the same sensor.

---

## Layer 4 — UI

> Can be developed in parallel with layers 2–3 once task 2 (LEDC) is done.

### 7. TFT screen content `src/ui.cpp` ✅ loading-screen UI + optional camera-verification screen
- [x] **Design decision — loading screen, not a live dashboard.** The TFT shows a set-target screen, a "Mixing…" loading screen with a simple spinner, a done screen, and (new) an on-demand camera-verification screen — no live PSD/IQR/stroke-count readout during a run. Raw sensor data and diagnostics are a BLE-only concern (`ble_debug.cpp`'s `FORCE`/`TURB`/`UAS`/`FIT`/`CAPTURE` commands) by project decision, not something duplicated on-screen. See `README.md`'s Operational Workflow section.
- [x] Ported from `testing/display_ui_testing` onto **LovyanGFX** (`LGFX_Config.h`) — validated on the bench as the most responsive display library trialed, replacing the old TFT_eSPI setup.
- [x] States: set-target → running (loading) → done (result) → back to set-target, with a `VERIFYING` state reachable from set-target or done (encoder long-press) that requests one RPi capture and shows median/IQR (or a timeout notice) — see task 9. Plus a persistent error screen if homing fails at boot (`ui_show_error()`).
- [ ] Live PSD trend graph idea from the old TFT_eSPI single-screen design is **dropped**, not carried forward — it doesn't fit a loading-screen UI. If a future revision wants a graph (or the annotated-JPEG display mentioned in task 4), it belongs alongside the verification screen, not as a continuous readout.

### 8. Rotary encoder quadrature decode `src/ui.cpp` ✅
- [x] `CHANGE` interrupts attached to GPIO16 (EC11_A) and GPIO17 (EC11_B), shared ISR reading both pins
- [x] Buxton-table quadrature decode in ISR (`_isrEncoder()`, ported from `testing/display_ui_testing`'s `encoder_driver.cpp`), accumulates into a volatile delta consumed in `ui_update()`
- [x] Encoder adjusts target particle size setpoint, 5µm/detent, clamped to 50–1000µm (`config.h`); only active on the set-target screen
- [x] Encoder's own push-switch (EC11_SW, GPIO18) is the confirm/start input — see task 9, this replaces BTN1's old start function

### 9. Button handling + debounce `src/ui.cpp` ✅ BTN1 (stop/e-stop) + EC11_SW (confirm/start/verify)
- [x] **Design decision — BTN1 is stop-only, no start function.** Previous firmware overloaded BTN1 with start (and used a since-removed BTN2 for stop). This build gives BTN1 exactly one job — short press = graceful stop (`scheduler_stop()`), held ≥`BTN1_LONGPRESS_MS` (800ms, `config.h`) = emergency stop (`scheduler_emergency_stop()`), fired the instant the hold threshold crosses rather than waiting for release.
- [x] EC11_SW (GPIO18) debounced separately, now with its own short/long distinction (`EC11_SW_LONGPRESS_MS`, 800ms) mirroring BTN1's pattern: short press confirms setpoint + starts a run on the set-target screen (or returns to set-target from the done/verify screens); held long triggers an optional camera verification (`rpi_request_capture()`) from the set-target or done screens. No-op during a run either way.
- [x] Automatic HX711 over-force (`force_sensor_estop_tripped()`, `main.cpp` loop) calls the exact same `scheduler_emergency_stop()` as the button — one kill path, not two. See `CALIBRATION.md` §4/§8 for the force threshold, which is still a placeholder.

### 10. XPT2046 touch input — REMOVED FROM SCOPE
- [x] **Design decision — no touch UI.** Encoder + one dedicated stop button covers the full operational workflow (see README); touch calibration risk isn't worth taking on. `PIN_TOUCH_CS`/`PIN_TOUCH_DO` remain defined in `config.h` (the pins are physically present per the v3.4 board) but nothing in firmware drives them.

### 11. Homing routine `src/motors.cpp` ✅
- [x] Both motors home simultaneously — drive at `HOMING_STEP_HZ` (500 Hz) toward limit
- [x] ISR kills LEDC on trip; main loop polls both flags with 30s timeout
- [x] Back-off: timed reverse at same speed for `HOMING_BACKOFF_STEPS / HOMING_STEP_HZ` ms
- [x] `motors_home()` called in `setup()` after all inits; `scheduler_update()` and `scheduler_start()` both guard on `motors_is_homed()`
- [x] On homing failure, `main.cpp` now calls `ui_show_error()` instead of silently continuing — the board halts on a persistent fault screen rather than letting a run start on an un-trusted stroke position
- [x] HARDWARE NOTE: `HOMING_FORWARD = false` assumed — verify limit switch end on real hardware

### 12. Stroke counter `src/motors.cpp` ✅
- [x] `motor_increment_stroke()` — the scheduler calls this after each complete forward+return cycle
- [x] `motor_get_stroke_count()` / `motor_reset_stroke_count()` — reset on homing
- [x] Counter reset to 0 at end of successful `motors_home()`
- [x] Also the `N` in the breakage model (`calibration.cpp`'s `calib_breakage_add_point()`) — every CV measurement is tagged with the stroke count at the time it arrived

### 13. Turbidity + force sensor bring-up `src/turbidity.cpp`, `src/force_sensor.cpp` ✅ read paths in place
- [x] Turbidity: I2C bus init (GPIO3/43, 400kHz), APDS9960 ALS clear-channel read, MAX30102 FIFO backscatter read — both closed-loop fusion inputs (`scheduler.cpp`, task 6) as well as streamed via `TURB ON` (BLE) for diagnostics
- [x] Force: shared-clock HX711 bit-bang driver for both channels, raw counts converted via `calibration.h`, streamed via `FORCE ON` (BLE) — both a fusion input and an independent e-stop safety input
- [ ] **BLOCKING before either is more than a raw-count stream** — see `CALIBRATION.md` §3 (turbidity baselines) and §4 (HX711 tare/scale/e-stop threshold). None of these have been measured against real hardware yet, and the fusion table (task 6) needs both baselines locked first (baselines change the ratio calculation the fusion table's columns are built from).

---

## Verification gates

Complete these checks in order before closing each layer.

| After task | What to verify |
|---|---|
| 1 | SG_RESULT responds under manual motor load — required before trusting it for anything, even diagnostically |
| 2 | Both motors step cleanly at target RPM; limit switch trips kill motion immediately |
| 3 | UAS ADC reading shifts measurably between air and slurry-filled syringe |
| 4 | BLE log shows correct median/IQR values parsed after a `CAPTURE` request (or the UI's encoder long-press) — not automatically, since CV is on-demand now |
| 5 | Attenuation ratio stable at baseline, changes monotonically as slurry thickens |
| 6 | The BLE `FUSION` command shows all four channels as `trusted` (not `excluded`) once `SENSOR_CAL_TABLE` is filled in, and the fused estimate tracks a mixing run's actual progress sensibly (decreasing toward target, not jumping around). A full run stops on `scheduler_target_reached()` with `scheduler_hit_safety_cap() == false`, and a camera verification afterward confirms the achieved size is reasonably close to target. |
| 13 | `FORCE ON`/`TURB ON` show plausible, stable numbers with the syringe empty; HX711 e-stop trips reliably on a manual obstruction test before trusting it unattended |

---

## Hardware checklist — things to confirm or calibrate on real hardware

Work through these in order. Items marked **BLOCKING** must be resolved before the system can run reliably.

### Before first power-on
- [ ] **BLOCKING** — TMC2209 VDD voltage: design brief §6.6 says "NOT CONFIRMED — 3.3V assumed safe." Check purchased module schematic before applying power.
- [ ] Motor connector pin order A1/A2/B1/B2: physically verify wiring harness matches J4/J5 pin order `OA1 NC OA2 OB1 NC OB2` (design brief §9).

### At first power-on (BLE log checks)
- [ ] **BLOCKING** — BLE log shows `"TMC addr 0: SpreadCycle OK"` and `"TMC addr 1: SpreadCycle OK"` at boot. If either says FAILED, stop — SG_RESULT data will be meaningless.
- [ ] BLE log shows `"UAS: init OK, baseline=XXX mV"` — confirm baseline is non-zero (>50 mV) with the AD9833 1MHz signal present.
- [ ] **BLOCKING** — AD9833 MCLK: assumed 25MHz in firmware (`config.h`). Confirm the actual clock source on the PCB. If MCLK differs, update the constructor argument in `uas.cpp:15`.

### Motor tuning
- [ ] `HOMING_FORWARD = false` (`config.h`): confirm which physical end of travel has the limit switch. Flip to `true` if motors jog the wrong way during homing.
- [ ] `HOMING_BACKOFF_STEPS = 200` (`config.h`): after homing, verify the plunger has fully cleared the limit switch. Increase if the switch stays triggered after back-off.
- [ ] `irun = 20` (~62% RMS, `motors.cpp`): run a syringe-loaded stroke cycle and check motor temperature. Reduce if hot, increase if losing steps.
- [ ] `ihold = 10` (~31% RMS, `motors.cpp`): reduce further if motors are warm while idle between strokes.

### Sensing validation
- [ ] **BLOCKING** — SG_RESULT under load: manually resist a motor shaft while stepping. Confirm `motor_sg_result()` value drops (lower = more load). It's diagnostic-only (not a fusion input), but a broken StallGuard reading is still worth catching early.
- [ ] **BLOCKING** — UAS attenuation shift: fill syringe with saline, recalibrate baseline, then add gelatin slurry. Confirm `uas_get_attenuation(freq_idx)` drops below 0.95 at each swept frequency. If no change, check transducer coupling and envelope detector output on oscilloscope.
- [ ] **BLOCKING** — Turbidity I2C scan: `TURB ON` shows both `als=...(ok)` and `...(ok)` for MAX30102. If either says `NOT FOUND`, check J15 wiring/pull-ups before anything else in that path.
- [ ] **BLOCKING** — HX711 tare/scale/e-stop: see `CALIBRATION.md` §4 in full — do not run an unattended mixing cycle until the e-stop threshold is set from real peak-force data, not a guessed round number.
- [ ] **Watch for RPi packet format changes.** The CV pipeline advisory recommends switching from bounding-box detection to instance segmentation and from a simple diameter to Equivalent Circular Diameter (+ Feret/solidity). If the RPi side adds fields beyond `median_um`/`iqr_um`, note that `rpi_uart.cpp`'s `sscanf(_buf, "SIZE %d %d", ...)` parser will silently ignore any extra trailing fields rather than erroring — new metrics (Feret, solidity) would arrive over UART but never reach firmware until the parser and `rpi_uart.h` getters are explicitly extended for them.

### Sensor-fusion calibration — the 9-syringe bench session (after all BLOCKING items above are cleared)

See `CALIBRATION.md` §5 for the full procedure — summary:
- [ ] For each of the 9 reference syringes (known particle size spanning the target range): load it, let readings settle, run the BLE `FUSION` command, and copy the printed `uas`/`apds`/`max`/`force` values into that syringe's row in `SENSOR_CAL_TABLE` (`calibration.cpp`) alongside its known size.
- [ ] After all 9 rows are filled in, run `FUSION` again on a couple of the same syringes and confirm each channel reports `trusted`, not `excluded` — if a channel is excluded, its 9-point curve isn't monotonic (check the raw values for that column; that sensor may not be usable for this material/size range).
- [ ] **BLOCKING before this is trustworthy** — this table hasn't been populated yet (all zeros). Do not run an unattended mixing cycle relying on fusion until it has, and until you've confirmed at least `FUSION_MIN_CHANNELS_REQUIRED` (2) channels come back trusted.
- [ ] Re-run per material — Lyostypt ≠ Gelfoam-equivalent (see the technical advisory); don't assume one calibration table covers every test material. There's no equivalent of `FIT RESET` for this table yet (it's a compile-time array) — swapping materials means re-flashing with a new table, or extending this to a runtime-editable table if that becomes a frequent need.
- [ ] Cross-check the fused estimate against the (diagnostic-only) breakage-model fit (BLE `FIT`) and against camera verifications (BLE `CAPTURE`) during early runs — if the fusion estimate and CV disagree substantially and consistently, something in the bench table is off.
- [ ] Sanity-check `MIXING_MAX_STROKES_SAFETY_CAP` (calibration.h) against a real full-range run once the table is populated — it should sit comfortably above what a legitimate run takes, but low enough to still catch a degenerate/miscalibrated setup.

### Touch — not applicable
Touch input was removed from scope (task 10) — no calibration needed.

---

## Notes

- **SpreadCycle is required for StallGuard4.** The MKS TMC2209 V2.0 module has no SPREAD pin — enforcement is firmware-only. If this write is skipped or fails, SG_RESULT data is meaningless (it's diagnostic-only, not a fusion input, but still worth getting right).
- **No PID, but very much closed-loop.** `pid.cpp`/`pid.h` are deleted — replaced by `scheduler.cpp`/`scheduler.h` (Layer 3, task 6), which closes the loop on a live, 4-sensor fused size estimate (UAS + 2x turbidity + force) and stops with a debounced hysteresis check, not a proportional/integral/derivative controller. CV sizing is the one thing that's optional and on-demand (task 4), used only as an independent double-check — see `scheduler.h`'s header comment for the full rationale and history (an earlier pass of this task mistakenly went open-loop/feedforward entirely when CV was removed from the loop; that was corrected once the actual intent — close the loop on the other four sensors instead — was clarified).
- **SPI bus sharing:** AD9833 uses Mode 2 (~10MHz); the TFT (LovyanGFX) uses Mode 0 (20MHz max via ribbon). No touch/XPT2046 on this bus (task 10, removed from scope) and no MISO as of v3.3. Always deassert all CS lines before switching devices. See the integration note in `uas.cpp`'s `uas_init()` about the TFT and AD9833 now using separate SPI driver paths on the same physical GPIOs.
- **ADC1 only.** UAS ADC is on GPIO1 (ADC1_CH0). ADC2 cannot be used during BLE — do not move UAS to any ADC2 pin.
- **UART assignment:** TMC2209 uses UART1, GPIO4 TX / GPIO44 RX (genuinely separate pins as of v3.4, same shared bus node off-chip). RPi uses UART2 (GPIO47/48). Do not reassign either — they are different peripherals.
- **I2C:** turbidity sensors (APDS9960 0x39, MAX30102 0x57) share GPIO3/43, 400kHz — independent of every other bus on the board.
- **Two separate BLE services exist in this project** — this firmware's `EMBO-Debug` (Nordic UART, diagnostics only) and `testing/PCB_Test_Firmware_v3_4`'s `EMBO-PCB-Test-v3.4` (bench bring-up dashboard). They are not interchangeable — see `firmware/esp32/README.md`'s BLE debug commands section.
- **Suggested solo order:** 1 → 2 → 3 → 4 → 5 → 6 → 13 → 7 → 8 → 9 (10 is out of scope)
- **Suggested split if two people:** person A does 1–6 and 13; person B does 7–9 starting after task 2 is done.

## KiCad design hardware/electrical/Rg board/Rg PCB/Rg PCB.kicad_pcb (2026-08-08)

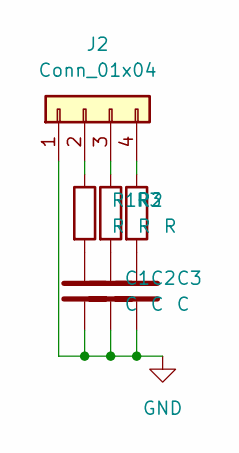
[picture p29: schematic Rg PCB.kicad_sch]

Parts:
C1, C2, C3: C; C_Disc_D5.0mm_W2.5mm_P5.00mm
J2: Conn_01x04; PinHeader_1x04_P2.54mm_Vertical
R1, R2, R3: R; R_Axial_DIN0207_L6.3mm_D2.5mm_P7.62mm_Horizontal

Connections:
GND: C1.2, C2.2, C3.2, J2.1
unnamed: C1.1, R1.2
unnamed: C2.1, R2.2
unnamed: C3.1, R3.2
unnamed: J2.2, R1.1
unnamed: J2.3, R2.1
unnamed: J2.4, R3.1

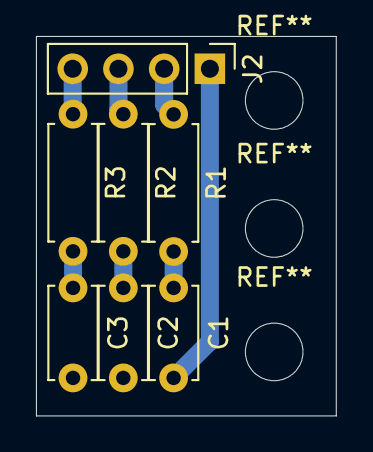
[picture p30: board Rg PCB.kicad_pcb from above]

Board: 2 copper layers, 16.7 x 21.1 mm, 7 parts (0 on the bottom side), 7 nets.

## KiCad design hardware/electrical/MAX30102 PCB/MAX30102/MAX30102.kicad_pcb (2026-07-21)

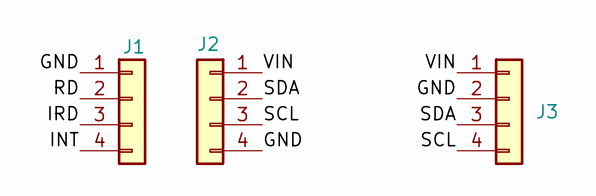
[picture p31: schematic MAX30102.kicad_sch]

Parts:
J1, J2: Conn_01x04; PinSocket_1x04_P2.54mm_Vertical
J3: Conn_01x04; JST_XH_B4B-XH-A_1x04_P2.50mm_Vertical

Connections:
/GND: J1.1, J2.4, J3.2
/INT: J1.4
/IRD: J1.3
/RD: J1.2
/SCL: J2.3, J3.4
/SDA: J2.2, J3.3
/VIN: J2.1, J3.1

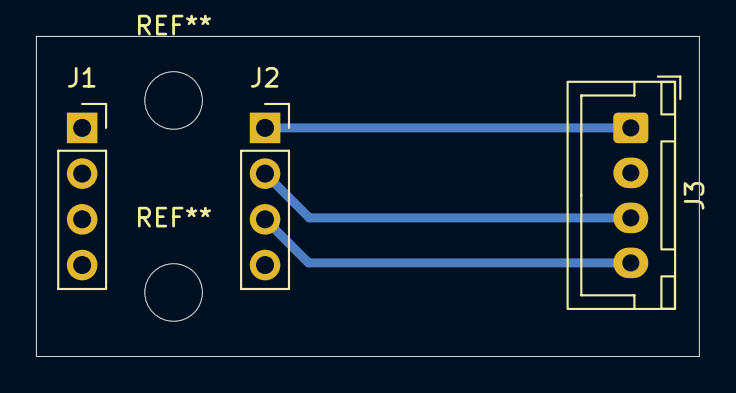
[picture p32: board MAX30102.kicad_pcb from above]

Board: 2 copper layers, 36.8 x 17.8 mm, 3 parts (0 on the bottom side), 4 nets.

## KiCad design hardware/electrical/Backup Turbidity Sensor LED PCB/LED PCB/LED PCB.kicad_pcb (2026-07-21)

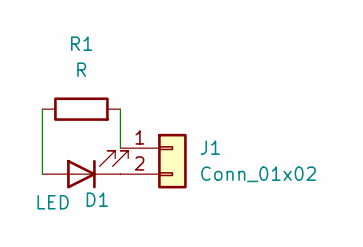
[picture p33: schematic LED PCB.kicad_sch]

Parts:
D1: LED; LED_D5.0mm
J1: Conn_01x02; JST_XH_B2B-XH-A_1x02_P2.50mm_Vertical
R1: R; R_Axial_DIN0207_L6.3mm_D2.5mm_P10.16mm_Horizontal

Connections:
unnamed: D1.2 (A), R1.1
unnamed: D1.1 (K), J1.2
unnamed: J1.1, R1.2

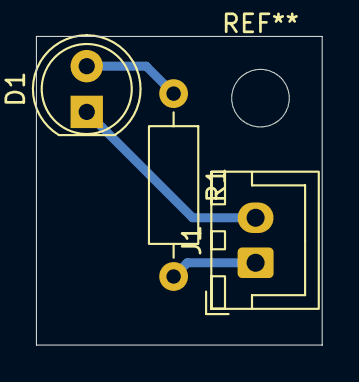
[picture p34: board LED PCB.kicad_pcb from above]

Board: 2 copper layers, 15.9 x 17.1 mm, 3 parts (0 on the bottom side), 3 nets.

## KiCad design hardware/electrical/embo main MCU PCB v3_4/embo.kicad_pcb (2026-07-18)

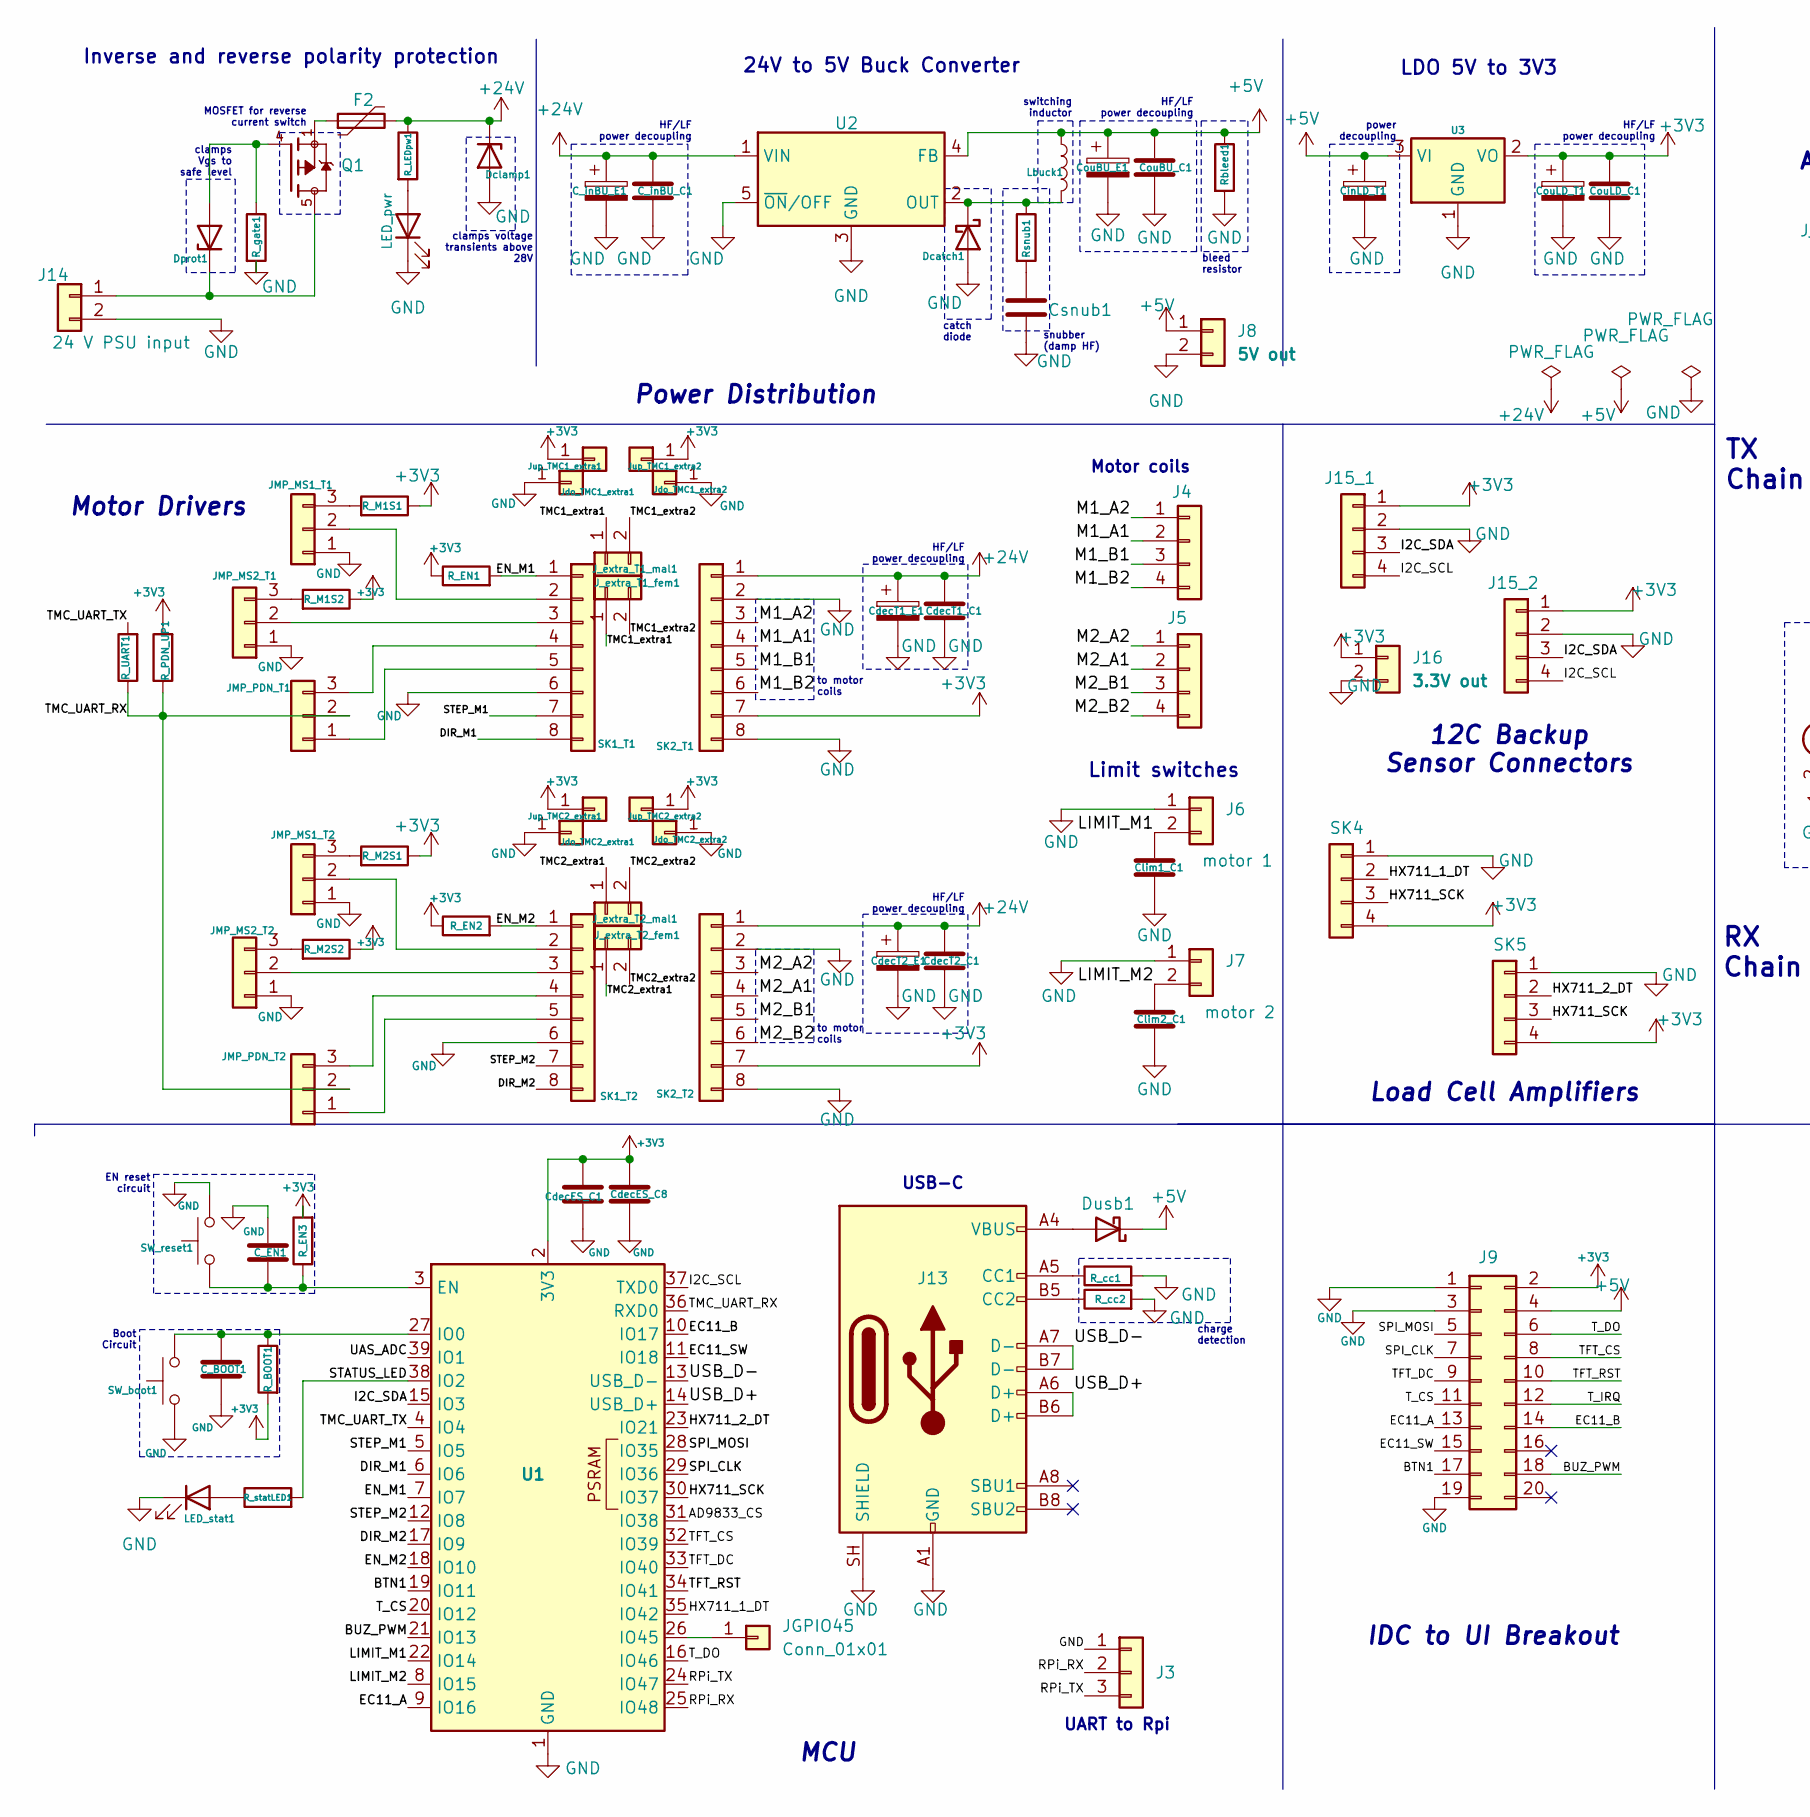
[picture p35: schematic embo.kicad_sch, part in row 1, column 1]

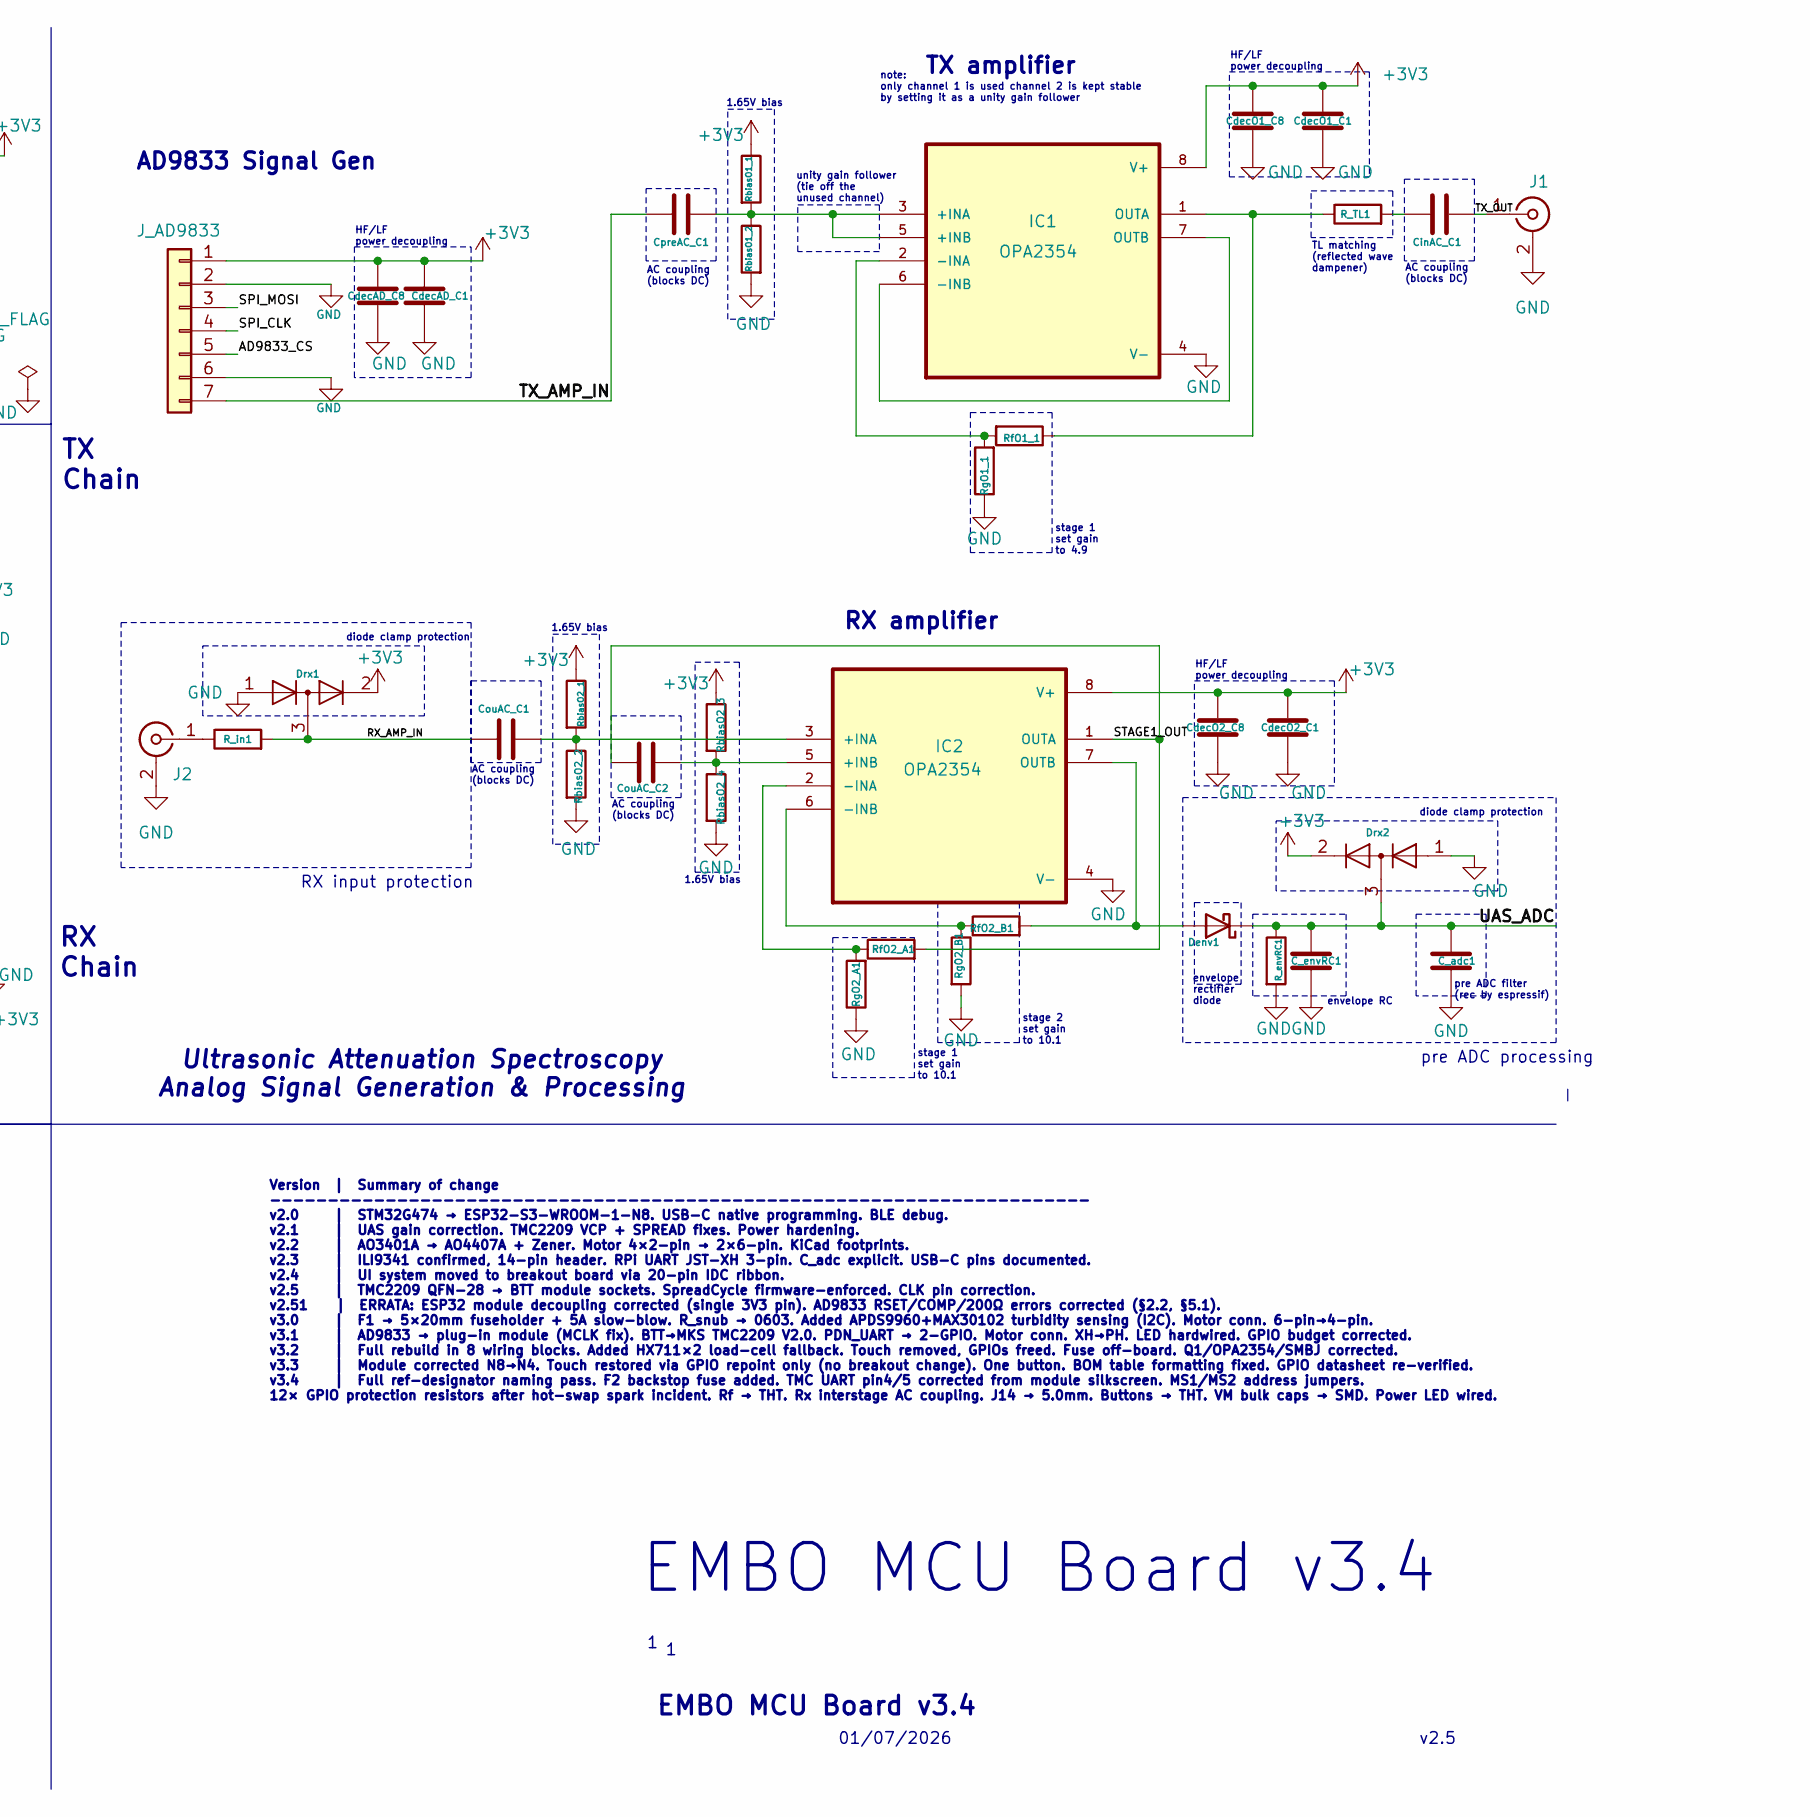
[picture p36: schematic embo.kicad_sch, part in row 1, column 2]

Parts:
C_BOOT1: 100nF X7R; C_0402_1005Metric_Pad0.74x0.62mm_HandSolder
C_EN1: 1µF X7R; C_0402_1005Metric_Pad0.74x0.62mm_HandSolder
C_adc1: 100nF X7R; C_0402_1005Metric_Pad0.74x0.62mm_HandSolder
C_envRC1: 10nF X7R; C_0402_1005Metric
C_inBU_C1: 100nF X7R; C_0402_1005Metric_Pad0.74x0.62mm_HandSolder
C_inBU_E1: 100 µF 50 V radial; C_Radial_D8.0mm_H11.5mm_P3.50mm
CdecAD_C1: 100nF X7R; C_0402_1005Metric_Pad0.74x0.62mm_HandSolder
CdecAD_C8: 10µF X5R 0805; C_0805_2012Metric
CdecES_C1: 100nF X7R; C_0402_1005Metric_Pad0.74x0.62mm_HandSolder
CdecES_C8: 10µF X5R 0805; C_0805_2012Metric
CdecO1_C1, CdecO2_C1: 100nF X7R; C_0402_1005Metric_Pad0.74x0.62mm_HandSolder
CdecO1_C8, CdecO2_C8: 10µF X5R 0805; C_0805_2012Metric
CdecT1_C1, CdecT2_C1: 100nF X7R; C_0402_1005Metric_Pad0.74x0.62mm_HandSolder
CdecT1_E1, CdecT2_E1: 100µF 35V electrolytic radial; CHEMI-HA0
CinAC_C1: 100nF X7R; C_0402_1005Metric_Pad0.74x0.62mm_HandSolder
CinLD_T1: 10µF 10V tantalum Case A; CP_EIA-3216-18_Kemet-A_HandSolder
Clim1_C1, Clim2_C1: 100nF X7R; C_0402_1005Metric_Pad0.74x0.62mm_HandSolder
CouAC_C1, CouAC_C2: 100nF X7R; C_0402_1005Metric_Pad0.74x0.62mm_HandSolder
CouBU_C1: 100nF X7R; C_0402_1005Metric_Pad0.74x0.62mm_HandSolder
CouBU_E1: 220µF 10V low-ESR electrolytic radial; C_Radial_D8.0mm_H11.5mm_P3.50mm
CouLD_C1: 100nF X7R; C_0402_1005Metric_Pad0.74x0.62mm_HandSolder
CouLD_T1: 10µF 10V tantalum Case A; CP_EIA-3216-18_Kemet-A_HandSolder
CpreAC_C1: 100nF X7R; C_0402_1005Metric_Pad0.74x0.62mm_HandSolder
Csnub1: 1nF X7R; C_0402_1005Metric_Pad0.74x0.62mm_HandSolder
Dcatch1: SS34A; D_SMA
Dclamp1: SMBJ28A; D_SMA
Denv1: BAT54; D_SOD-123
Dprot1: BZX84C15, 15 V Zener, SOT-23; SOT-23
Drx1, Drx2: BAV99; SOT-23
Dusb1: 1N5819; D_SOD-123
F2: 5A littlefuse; Fuse_2512_6332Metric
IC1, IC2: OPA2354; SOIC-8_3.9x4.9mm_P1.27mm; DigiKey_Part_Number 296-25648-1-ND
J1, J2: Conn_Coaxial; SMA_Molex_73251-1153_EdgeMount_Horizontal
J3: Conn_01x03; JST_XH_B3B-XH-A_1x03_P2.50mm_Vertical
J4, J5, J15_1, J15_2: Conn_01x04; JST_XH_B4B-XH-A_1x04_P2.50mm_Vertical
J6: motor 1; JST_XH_B2B-XH-A_1x02_P2.50mm_Vertical
J7: motor 2; JST_XH_B2B-XH-A_1x02_P2.50mm_Vertical
J8: 5V out; JST_XH_B2B-XH-A_1x02_P2.50mm_Vertical
J9: Conn_02x10_Odd_Even; IDC-Header_2x10_P2.54mm_Vertical
J13: USB_C_Receptacle_USB2.0_16P; USB_C_Receptacle_HRO_TYPE-C-31-M-12
J14: 24 V PSU input; TerminalBlock_Phoenix_MKDS-1,5-2-5.08_1x02_P5.08mm_Horizont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
J16: 3.3V out; JST_XH_B2B-XH-A_1x02_P2.50mm_Vertical
JGPIO45: Conn_01x01; PinHeader_1x01_P2.54mm_Vertical
JMP_MS1_T1, JMP_MS1_T2, JMP_MS2_T1, JMP_MS2_T2: Conn_01x03; PinHeader_1x03_P2.54mm_Vertical
JMP_PDN_T1, JMP_PDN_T2: Conn_01x03; PinHeader_1x03_P2.54mm_Vertical
J_AD9833: Conn_01x07; PinSocket_1x07_P2.54mm_Vertical
J_extra_T1_fem1, J_extra_T2_fem1: Conn_01x02; PinSocket_1x02_P2.54mm_Vertical
J_extra_T1_mal1, J_extra_T2_mal1: Conn_01x02; PinHeader_1x02_P2.54mm_Vertical
Jdo_TMC1_extra1, Jdo_TMC1_extra2, Jdo_TMC2_extra1, Jdo_TMC2_extra2: Conn_01x01; PinHeader_1x01_P2.54mm_Vertical
Jup_TMC1_extra1, Jup_TMC1_extra2, Jup_TMC2_extra1, Jup_TMC2_extra2: Conn_01x01; PinHeader_1x01_P2.54mm_Vertical
LED_pwr1: LED_pwr; LED_0805_2012Metric
LED_stat1: green LED; LED_0805_2012Metric
Lbuck1: 100µH; L_Bourns_SRR1260
Q1: AO4407A; SOIC-8_3.9x4.9mm_P1.27mm; PARTREV I
R_BOOT1: 10kΩ 0402; R_0402_1005Metric_Pad0.72x0.64mm_HandSolder
R_EN1, R_EN2, R_EN3: 10kΩ 0402; R_0402_1005Metric_Pad0.72x0.64mm_HandSolder
R_LEDpw1: 10kΩ 0402; R_0402_1005Metric_Pad0.72x0.64mm_HandSolder
R_M1S1, R_M1S2, R_M2S1, R_M2S2: 10kΩ 0402; R_0402_1005Metric_Pad0.72x0.64mm_HandSolder
R_PDN_UP1: 10kΩ 0402; R_0402_1005Metric_Pad0.72x0.64mm_HandSolder
R_TL1: 47Ω; R_0402_1005Metric_Pad0.72x0.64mm_HandSolder
R_UART1: 1kΩ 0402; R_0402_1005Metric_Pad0.72x0.64mm_HandSolder
R_cc1, R_cc2: 5.1kΩ; R_0402_1005Metric_Pad0.72x0.64mm_HandSolder
R_envRC1: 10kΩ 0402; R_0402_1005Metric_Pad0.72x0.64mm_HandSolder
R_gate1: 10kΩ 0402; R_0402_1005Metric_Pad0.72x0.64mm_HandSolder
R_in1: 100Ω 0402; R_0402_1005Metric_Pad0.72x0.64mm_HandSolder
R_statLED1: 330Ω; R_0402_1005Metric_Pad0.72x0.64mm_HandSolder
RbiasO1_1, RbiasO1_2, RbiasO2_1, RbiasO2_2, RbiasO2_3, RbiasO2_4: 10kΩ 0402; R_0402_1005Metric_Pad0.72x0.64mm_HandSolder
Rbleed1: 4.7kΩ; R_0402_1005Metric_Pad0.72x0.64mm_HandSolder
RfO1_1: 390Ω; R_Axial_DIN0207_L6.3mm_D2.5mm_P10.16mm_Horizontal
RfO2_A1, RfO2_B1: 910Ω; R_0402_1005Metric_Pad0.72x0.64mm_HandSolder
RgO1_1, RgO2_A1, RgO2_B1: 100Ω; R_0402_1005Metric_Pad0.72x0.64mm_HandSolder
Rsnub1: 10kΩ 0402; R_0402_1005Metric_Pad0.72x0.64mm_HandSolder
SK1_T1, SK1_T2, SK2_T1, SK2_T2: Conn_01x08; PinSocket_1x08_P2.54mm_Vertical
SK4, SK5: Conn_01x04; PinSocket_1x04_P2.54mm_Vertical
SW_boot1: 6×6mm tactile; SW_PUSH_6mm
SW_reset1: 6×6mm tactile; SW_PUSH_6mm
U1: ESP32-S3-WROOM-1
U2: LM2596S-5; TO-263-5_TabPin3
U3: AMS1117-3.3; SOT-223-3_TabPin2

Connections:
+3V3: CdecAD_C1.1, CdecAD_C8.2, CdecES_C1.2, CdecES_C8.2, CdecO1_C1.1, CdecO1_C8.1, CdecO2_C1.1, CdecO2_C8.1, CouLD_C1.1, CouLD_T1.1, Drx1.2 (A), Drx2.2 (A), IC1.8 (V+), IC2.8 (V+), J9.2, J15_1.1, J15_2.1, J16.1, J_AD9833.1, Jup_TMC1_extra1.1 (Pin_1_1), Jup_TMC1_extra2.1 (Pin_1_1), Jup_TMC2_extra1.1 (Pin_1_1), Jup_TMC2_extra2.1 (Pin_1_1), R_BOOT1.2, R_EN1.1, R_EN2.1, R_EN3.2, R_M1S1.1, R_M1S2.1, R_M2S1.1, R_M2S2.1, R_PDN_UP1.2, RbiasO1_1.1, RbiasO2_1.1, RbiasO2_3.1, SK2_T1.7, SK2_T2.7, SK4.4, SK5.4, U1.2 (3V3), U3.2 (VO)
+5V: CinLD_T1.1, CouBU_C1.1, CouBU_E1.1, Dusb1.1 (K), J8.1, J9.4, Lbuck1.1, Rbleed1.1, U2.4 (FB), U3.3 (VI)
+24V: C_inBU_C1.1, C_inBU_E1.1, CdecT1_C1.1, CdecT1_E1.1, CdecT2_C1.1, CdecT2_E1.1, Dclamp1.1 (K), F2.2, R_LEDpw1.1, SK2_T1.1, SK2_T2.1, U2.1 (VIN)
/AD9833_CS: J_AD9833.5, U1.31 (IO38)
/BTN1: J9.17, U1.19 (IO11)
/BUZ_PWM: J9.18, U1.21 (IO13)
/DIR_M1: SK1_T1.8, U1.6 (IO6)
/DIR_M2: SK1_T2.8, U1.17 (IO9)
/EC11_A: J9.13, U1.9 (IO16)
/EC11_B: J9.14, U1.10 (IO17)
/EC11_SW: J9.15, U1.11 (IO18)
/EN_M1: R_EN1.2, SK1_T1.1, U1.7 (IO7)
/EN_M2: R_EN2.2, SK1_T2.1, U1.18 (IO10)
/HX711_1_DT: SK4.2, U1.35 (IO42)
/HX711_2_DT: SK5.2, U1.23 (IO21)
/HX711_SCK: SK4.3, SK5.3, U1.30 (IO37)
/I2C_SCL: J15_1.4, J15_2.4, U1.37 (TXD0)
/I2C_SDA: J15_1.3, J15_2.3, U1.15 (IO3)
/LIMIT_M1: Clim1_C1.1, J6.2, U1.22 (IO14)
/LIMIT_M2: Clim2_C1.1, J7.2, U1.8 (IO15)
/M1_A1: J4.2, SK2_T1.4
/M1_A2: J4.1, SK2_T1.3
/M1_B1: J4.3, SK2_T1.5
/M1_B2: J4.4, SK2_T1.6
/M2_A1: J5.2, SK2_T2.4
/M2_A2: J5.1, SK2_T2.3
/M2_B1: J5.3, SK2_T2.5
/M2_B2: J5.4, SK2_T2.6
/RPi_RX: J3.2, U1.25 (IO48)
/RPi_TX: J3.3, U1.24 (IO47)
/RX_AMP_IN: CouAC_C1.1, Drx1.3 (K), R_in1.2
/SPI_CLK: J9.7, J_AD9833.4, U1.29 (IO36)
/SPI_MOSI: J9.5, J_AD9833.3, U1.28 (IO35)
/STAGE1_OUT: CouAC_C2.1, IC2.1 (OUTA), RfO2_A1.2
/STATUS_LED: R_statLED1.2, U1.38 (IO2)
/STEP_M1: SK1_T1.7, U1.5 (IO5)
/STEP_M2: SK1_T2.7, U1.12 (IO8)
/TFT_CS: J9.8, U1.32 (IO39)
/TFT_DC: J9.9, U1.33 (IO40)
/TFT_RST: J9.10, U1.34 (IO41)
/TMC1_extra1: J_extra_T1_fem1.1, J_extra_T1_mal1.1
/TMC1_extra2: J_extra_T1_fem1.2, J_extra_T1_mal1.2
/TMC2_extra1: J_extra_T2_fem1.1, J_extra_T2_mal1.1
/TMC2_extra2: J_extra_T2_fem1.2, J_extra_T2_mal1.2
/TMC_UART_RX: JMP_PDN_T1.2, JMP_PDN_T2.2, R_PDN_UP1.1, R_UART1.1, U1.36 (RXD0)
/TMC_UART_TX: R_UART1.2, U1.4 (IO4)
/TX_AMP_IN: CpreAC_C1.1, J_AD9833.7
/TX_OUT: CinAC_C1.2, J1.1 (In)
/T_CS: J9.11, U1.20 (IO12)
/T_DO: J9.6, U1.16 (IO46)
/T_IRQ: J9.12
/UAS_ADC: C_adc1.1, C_envRC1.1, Denv1.1 (K), Drx2.3 (K), R_envRC1.1, U1.39 (IO1)
/USB_D+: J13.A6 (D+), J13.B6 (D+), U1.14 (USB_D+)
/USB_D-: J13.A7 (D-), J13.B7 (D-), U1.13 (USB_D-)
GND: C_BOOT1.2, C_EN1.2, C_adc1.2, C_envRC1.2, C_inBU_C1.2, C_inBU_E1.2, CdecAD_C1.2, CdecAD_C8.1, CdecES_C1.1, CdecES_C8.1, CdecO1_C1.2, CdecO1_C8.2, CdecO2_C1.2, CdecO2_C8.2, CdecT1_C1.2, CdecT1_E1.2, CdecT2_C1.2, CdecT2_E1.2, CinLD_T1.2, Clim1_C1.2, Clim2_C1.2, CouBU_C1.2, CouBU_E1.2, CouLD_C1.2, CouLD_T1.2, Csnub1.2, Dcatch1.2 (A), Dclamp1.2 (A), Drx1.1 (K), Drx2.1 (K), IC1.4 (V-), IC2.4 (V-), J1.2 (Ext), J2.2 (Ext), J3.1, J6.1, J7.1, J8.2, J9.1, J9.3, J9.19, J13.A1 (GND), J13.A12 (GND), J13.B1 (GND), J13.B12 (GND), J13.SH (SHIELD), J14.2, J15_1.2, J15_2.2, J16.2, JMP_MS1_T1.1, JMP_MS1_T2.1, JMP_MS2_T1.1, JMP_MS2_T2.1, J_AD9833.2, J_AD9833.6, Jdo_TMC1_extra1.1 (Pin_1_1), Jdo_TMC1_extra2.1 (Pin_1_1), Jdo_TMC2_extra1.1 (Pin_1_1), Jdo_TMC2_extra2.1 (Pin_1_1), LED_pwr1.1 (K), LED_stat1.1 (K), R_cc1.2, R_cc2.2, R_envRC1.2, R_gate1.2, RbiasO1_2.2, RbiasO2_2.2, RbiasO2_4.2, Rbleed1.2, RgO1_1.1, RgO2_A1.1, RgO2_B1.2, SK1_T1.6, SK1_T2.6, SK2_T1.2, SK2_T1.8, SK2_T2.2, SK2_T2.8, SK4.1, SK5.1, SW_boot1.2, SW_reset1.2, U1.1 (GND), U1.40 (GND), U1.41 (GND), U2.3 (GND), U2.5 (~ON/OFF), U3.1 (GND)
unnamed: CinAC_C1.1, R_TL1.2
unnamed: Csnub1.1, Rsnub1.2
unnamed: Dcatch1.1 (K), Lbuck1.2, Rsnub1.1, U2.2 (OUT)
unnamed: Denv1.2 (A), IC2.7 (OUTB), RfO2_B1.2
unnamed: Dprot1.1 (A), Q1.4, R_gate1.1
unnamed: Dprot1.3 (K), J14.1, Q1.5, Q1.6, Q1.7, Q1.8
unnamed: Dusb1.2 (A), J13.A4 (VBUS), J13.A9 (VBUS), J13.B4 (VBUS), J13.B9 (VBUS)
unnamed: F2.1, Q1.1, Q1.2, Q1.3
unnamed: CpreAC_C1.2, IC1.3 (+INA), IC1.5 (+INB), RbiasO1_1.2, RbiasO1_2.1
unnamed: IC1.2 (-INA), RfO1_1.2, RgO1_1.2
unnamed: IC1.6 (-INB), IC1.7 (OUTB)
unnamed: IC1.1 (OUTA), R_TL1.1, RfO1_1.1
unnamed: CouAC_C1.2, IC2.3 (+INA), RbiasO2_1.2, RbiasO2_2.1
unnamed: CouAC_C2.2, IC2.5 (+INB), RbiasO2_3.2, RbiasO2_4.1
unnamed: IC2.2 (-INA), RfO2_A1.1, RgO2_A1.2
unnamed: IC2.6 (-INB), RfO2_B1.1, RgO2_B1.1
unnamed: J2.1 (In), R_in1.1
unnamed: J13.A5 (CC1), R_cc1.1
unnamed: J13.B5 (CC2), R_cc2.1
unnamed: JGPIO45.1 (Pin_1_1), U1.26 (IO45)
unnamed: JMP_MS1_T1.2, SK1_T1.2
unnamed: JMP_MS1_T1.3, R_M1S1.2
unnamed: JMP_MS1_T2.2, SK1_T2.2
unnamed: JMP_MS1_T2.3, R_M2S1.2
unnamed: JMP_MS2_T1.2, SK1_T1.3
unnamed: JMP_MS2_T1.3, R_M1S2.2
unnamed: JMP_MS2_T2.2, SK1_T2.3
unnamed: JMP_MS2_T2.3, R_M2S2.2
unnamed: JMP_PDN_T1.1, SK1_T1.5
unnamed: JMP_PDN_T1.3, SK1_T1.4
unnamed: JMP_PDN_T2.1, SK1_T2.5
unnamed: JMP_PDN_T2.3, SK1_T2.4
unnamed: LED_pwr1.2 (A), R_LEDpw1.2
unnamed: LED_stat1.2 (A), R_statLED1.1
unnamed: C_EN1.1, R_EN3.1, SW_reset1.1, U1.3 (EN)
unnamed: C_BOOT1.1, R_BOOT1.1, SW_boot1.1, U1.27 (IO0)

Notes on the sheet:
stage 1 set gain to 4.9
pre ADC processing
HF/LF power decoupling
AD9833 Signal Gen
HF/LF power decoupling
v2.5
RX Chain
note: only channel 1 is used channel 2 is kept stable by setting it as a unity gain follower
RX input protection
envelope rectifier diode
Version | Summary of change ----------------------------------------------------------------------- v2.0 | STM32G474 → ESP32-S3-WROOM-1-N8. USB-C native programming. BLE debug. v2.1 | UAS gain correction. TMC2209 VCP + SPREAD fixes. Power hardening. v2.2 | AO3401A → AO4407A + Zener. Motor 4×2-pin →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
EMBO MCU Board v3.4
envelope RC
AC coupling (blocks DC)
pre ADC filter (rec by espressif)
stage 1 set gain to 10.1
LDO 5V to 3V3
unity gain follower (tie off the unused channel)
catch diode
TL matching (reflected wave dampener)
EMBO MCU Board v3.4
UART to Rpi
snubber (damp HF)
1.65V bias
stage 2 set gain to 10.1
to motor coils
01/07/2026
24V to 5V Buck Converter
Boot Circuit
USB-C
RX amplifier
MCU
Load Cell Amplifiers
TX Chain
TX amplifier
12C Backup Sensor Connectors
clamps voltage transients above 28V
switching inductor
power decoupling
Inverse and reverse polarity protection

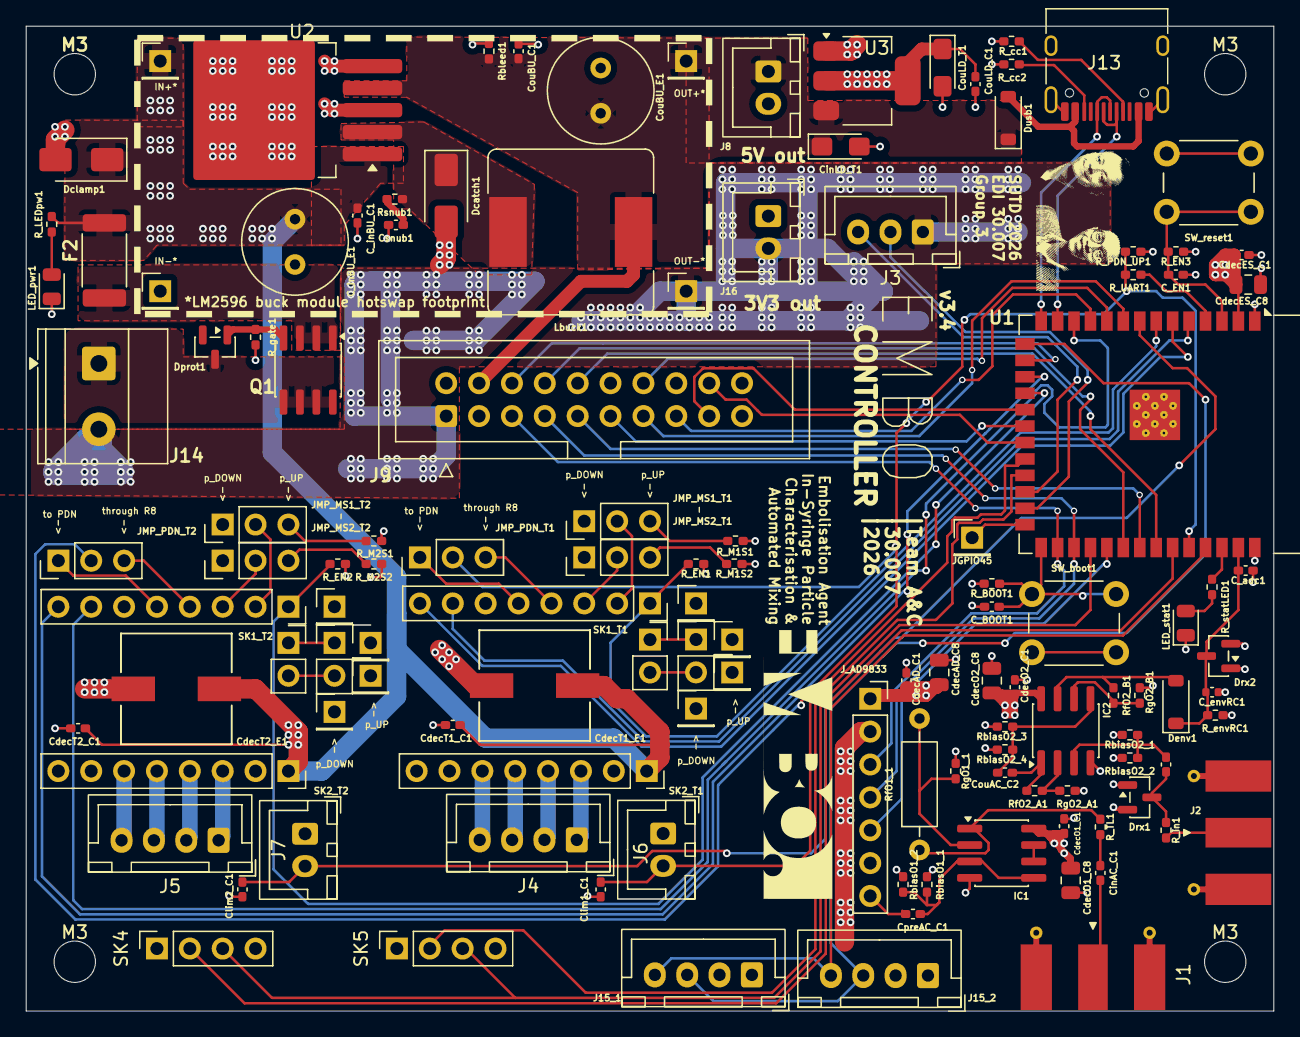
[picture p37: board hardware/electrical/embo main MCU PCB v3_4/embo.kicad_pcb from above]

Board: 4 copper layers, 96.4 x 76.1 mm, 125 parts (0 on the bottom side), 90 nets.

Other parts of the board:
M3, M3#2, M3#3, M3#4: MountingHole_3.2mm_M3

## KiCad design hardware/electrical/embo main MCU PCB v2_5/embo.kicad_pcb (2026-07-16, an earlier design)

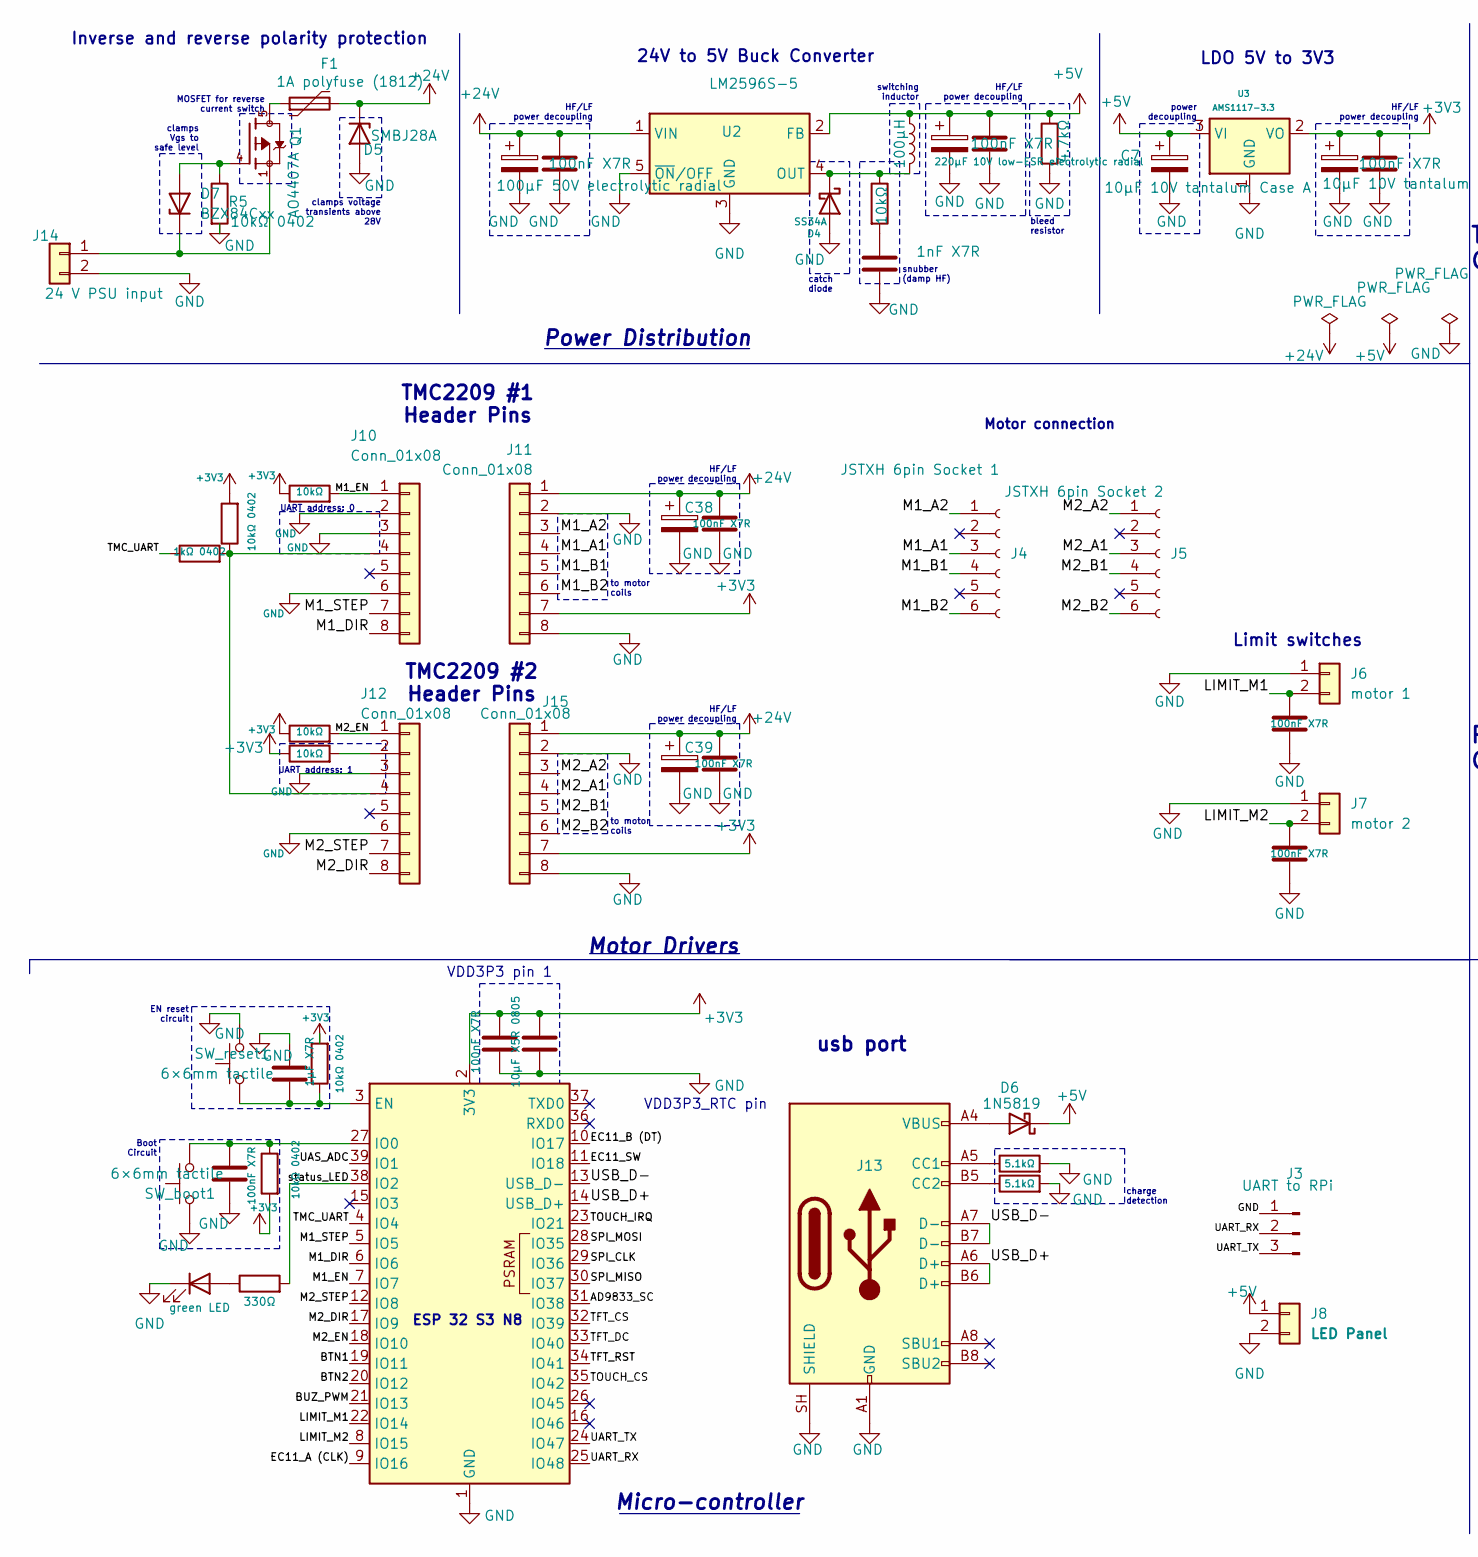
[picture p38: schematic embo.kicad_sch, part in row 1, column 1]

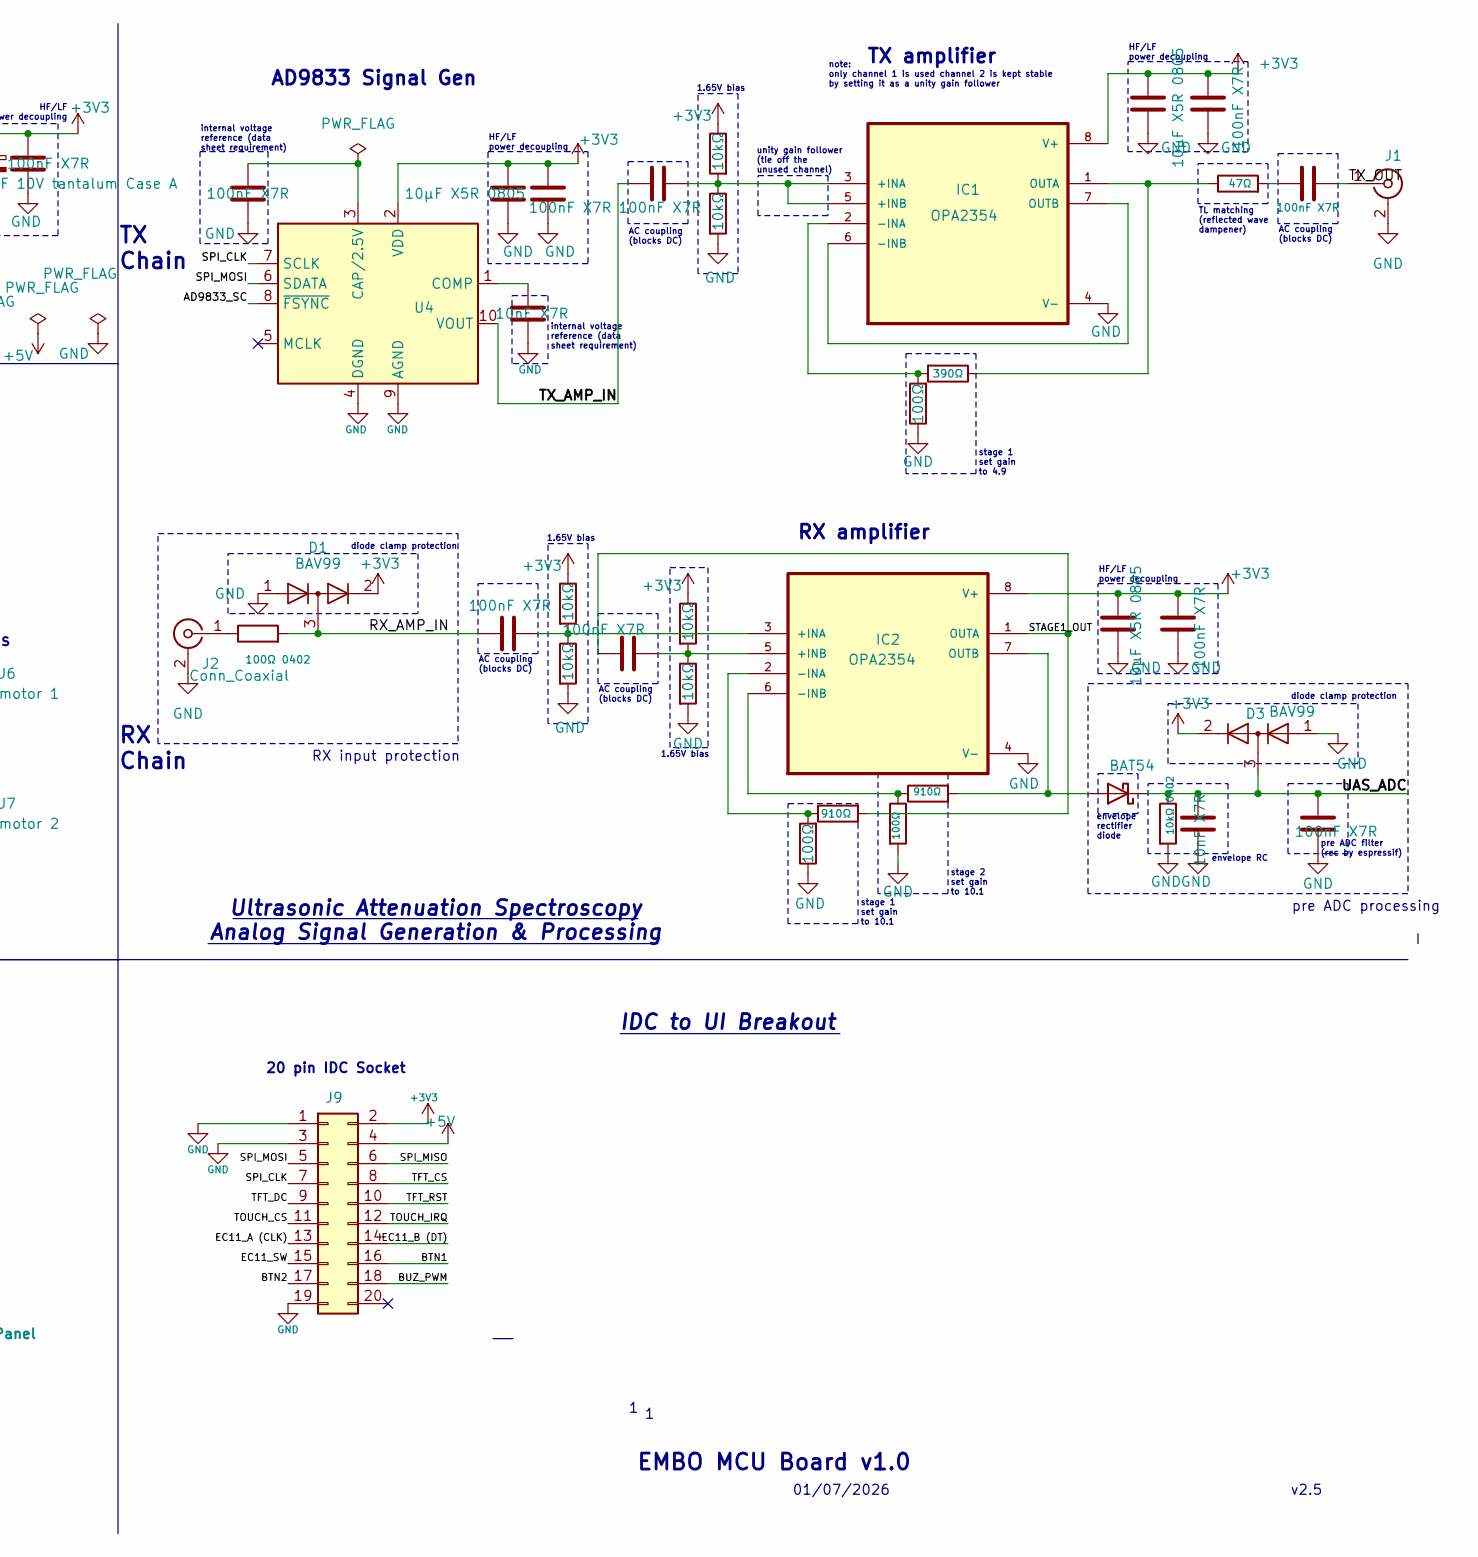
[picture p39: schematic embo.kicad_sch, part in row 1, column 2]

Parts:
C7, C11: 10µF 10V tantalum Case A; CP_EIA-3216-18_Kemet-A_HandSolder
C10: 1µF X7R; C_0402_1005Metric_Pad0.74x0.62mm_HandSolder
C12, C13, C17, C18, C20, C21, C22, C23, C25, C27, C30, C31, C35, C36, C41: 100nF X7R; C_0402_1005Metric_Pad0.74x0.62mm_HandSolder
C16: 100µF 50V electrolytic radial; C_Radial_D8.0mm_H11.5mm_P3.50mm
C19: 220µF 10V low-ESR electrolytic radial; C_Radial_D8.0mm_H11.5mm_P3.50mm
C24, C26, C28, C33: 10µF X5R 0805; C_0805_2012Metric
C34: 10nF X7R; C_0402_1005Metric
C38, C39: 100µF 35V electrolytic radial; C_Radial_D6.3mm_H7.0mm_P2.50mm
C_adc1: 100nF X7R; C_0402_1005Metric_Pad0.74x0.62mm_HandSolder
C_env1: 10nF X7R; C_0402_1005Metric
Cbuck1: 100nF X7R; C_0402_1005Metric_Pad0.74x0.62mm_HandSolder
Cbuckout1: 100nF X7R; C_0402_1005Metric_Pad0.74x0.62mm_HandSolder
Csnub1: 1nF X7R; C_0402_1005Metric_Pad0.74x0.62mm_HandSolder
D1, D3: BAV99; SOT-23
D2: BAT54; D_SOD-123
D4: SS34A; D_SMA
D5: SMBJ28A; D_SMA
D6: 1N5819; D_SOD-123
D7: BZX84Cxx; SOT-23
F1: 1A polyfuse (1812); Fuse_1812_4532Metric_Pad1.30x3.40mm_HandSolder
IC1, IC2: OPA2354; SOIC-8_3.9x4.9mm_P1.27mm; DigiKey_Part_Number 296-25648-1-ND
J1, J2: Conn_Coaxial; SMA_Molex_73251-1153_EdgeMount_Horizontal
J3: UART to RPi; JST_XH_B3B-XH-A_1x03_P2.50mm_Vertical
J4: JSTXH 6pin Socket 1; JST_XH_B6B-XH-A_1x06_P2.50mm_Vertical
J5: JSTXH 6pin Socket 2; JST_XH_B6B-XH-A_1x06_P2.50mm_Vertical
J6: motor 1; JST_XH_B2B-XH-A_1x02_P2.50mm_Vertical
J7: motor 2; JST_XH_B2B-XH-A_1x02_P2.50mm_Vertical
J8: LED Panel; JST_XH_B2B-XH-A_1x02_P2.50mm_Vertical
J9: Conn_02x10_Odd_Even; IDC-Header_2x10_P2.54mm_Vertical
J10, J11, J12, J15: Conn_01x08; PinSocket_1x08_P2.54mm_Vertical
J13: USB_C_Receptacle_USB2.0_16P; USB_C_Receptacle_HRO_TYPE-C-31-M-12
J14: 24 V PSU input; TerminalBlock_Phoenix_PT-1,5-2-3.5-H_1x02_P3.50mm_Horizontal
L1: 100µH; L_Bourns_SRR1260
LED_stat1: green LED; LED_0805_2012Metric
Q1: AO4407A; SOIC-8_3.9x4.9mm_P1.27mm; PARTREV I
R1, R9, R12, R21, R22, R28, R29, R38, R39: 10kΩ; R_0402_1005Metric_Pad0.72x0.64mm_HandSolder
R5, R40, R41: 10kΩ 0402; R_0402_1005Metric_Pad0.72x0.64mm_HandSolder
R6: 330Ω; R_0402_1005Metric_Pad0.72x0.64mm_HandSolder
R17, R18: 5.1kΩ; R_0402_1005Metric_Pad0.72x0.64mm_HandSolder
R19: 4.7kΩ; R_0402_1005Metric_Pad0.72x0.64mm_HandSolder
R26, R31, R37: 100Ω; R_0402_1005Metric_Pad0.72x0.64mm_HandSolder
R27, R35: 910Ω; R_0402_1005Metric_Pad0.72x0.64mm_HandSolder
R32: 47Ω; R_0402_1005Metric_Pad0.72x0.64mm_HandSolder
R33: 390Ω; R_0402_1005Metric_Pad0.72x0.64mm_HandSolder
R_PDN_UP1: 10kΩ 0402; R_0402_1005Metric_Pad0.72x0.64mm_HandSolder
R_UART1: 1kΩ 0402; R_0402_1005Metric_Pad0.72x0.64mm_HandSolder
R_env1: 10kΩ 0402; R_0402_1005Metric_Pad0.72x0.64mm_HandSolder
R_in1: 100Ω 0402; R_0402_1005Metric_Pad0.72x0.64mm_HandSolder
Rsnub1: 10kΩ; R_0402_1005Metric_Pad0.72x0.64mm_HandSolder
SW_boot1: 6×6mm tactile; SW_SPST_EVQP2_MiddlePushTravel_H2.5mm
SW_reset1: 6×6mm tactile; SW_SPST_EVQP2_MiddlePushTravel_H2.5mm
U1: ESP32-S3-WROOM-1
U2: LM2596S-5; TO-263-5_TabPin3
U3: AMS1117-3.3; SOT-223-3_TabPin2
U4: AD9833xRM; MSOP-10_3x3mm_P0.5mm

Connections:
+3V3: C11.1, C12.1, C22.2, C23.1, C24.1, C25.1, C26.1, C28.2, C31.1, C33.2, D1.2 (A), D3.2 (A), IC1.8 (V+), IC2.8 (V+), J9.2, J11.7, J15.7, R1.1, R9.1, R12.1, R21.1, R28.1, R38.1, R40.2, R41.2, R_PDN_UP1.2, U1.2 (3V3), U3.2 (VO), U4.2 (VDD)
+5V: C7.1, C19.1, Cbuckout1.1, D6.1 (K), J8.1, J9.4, L1.1, R19.1, U2.2 (FB), U3.3 (VI)
+24V: C13.1, C16.1, C36.1, C38.1, C39.1, Cbuck1.1, D5.1 (K), F1.2, J11.1, J15.1, U2.1 (VIN)
/AD9833_SC: U1.31 (IO38), U4.8 (~FSYNC)
/BTN1: J9.16, U1.19 (IO11)
/BTN2: J9.17, U1.20 (IO12)
/BUZ_PWM: J9.18, U1.21 (IO13)
/EC11_A (CLK): J9.13, U1.9 (IO16)
/EC11_B (DT): J9.14, U1.10 (IO17)
/EC11_SW: J9.15, U1.11 (IO18)
/LIMIT_M1: C17.1, J6.2, U1.22 (IO14)
/LIMIT_M2: C18.1, J7.2, U1.8 (IO15)
/M1_A1: J4.3, J11.4
/M1_A2: J4.1, J11.3
/M1_B1: J4.4, J11.5
/M1_B2: J4.6, J11.6
/M1_DIR: J10.8, U1.6 (IO6)
/M1_EN: J10.1, R1.2, U1.7 (IO7)
/M1_STEP: J10.7, U1.5 (IO5)
/M2_A1: J5.3, J15.4
/M2_A2: J5.1, J15.3
/M2_B1: J5.4, J15.5
/M2_B2: J5.6, J15.6
/M2_DIR: J12.8, U1.17 (IO9)
/M2_EN: J12.1, R9.2, U1.18 (IO10)
/M2_STEP: J12.7, U1.12 (IO8)
/RX_AMP_IN: C20.1, D1.3 (K), R_in1.2
/SPI_CLK: J9.7, U1.29 (IO36), U4.7 (SCLK)
/SPI_MISO: J9.6, U1.30 (IO37)
/SPI_MOSI: J9.5, U1.28 (IO35), U4.6 (SDATA)
/STAGE1_OUT: C21.1, IC2.1 (OUTA), R35.2
/TFT_CS: J9.8, U1.32 (IO39)
/TFT_DC: J9.9, U1.33 (IO40)
/TFT_RST: J9.10, U1.34 (IO41)
/TMC_UART: R_UART1.1, U1.4 (IO4)
/TOUCH_CS: J9.11, U1.35 (IO42)
/TOUCH_IRQ: J9.12, U1.23 (IO21)
/TX_AMP_IN: C35.1, U4.10 (VOUT)
/TX_OUT: C27.2, J1.1 (In)
/UART_RX: J3.2, U1.25 (IO48)
/UART_TX: J3.3, U1.24 (IO47)
/UAS_ADC: C_adc1.1, C_env1.1, D2.1 (K), D3.3 (K), R_env1.1, U1.39 (IO1)
/USB_D+: J13.A6 (D+), J13.B6 (D+), U1.14 (USB_D+)
/USB_D-: J13.A7 (D-), J13.B7 (D-), U1.13 (USB_D-)
/status_LED: R6.2, U1.38 (IO2)
GND: C7.2, C10.2, C11.2, C12.2, C13.2, C16.2, C17.2, C18.2, C19.2, C22.1, C23.2, C24.2, C25.2, C26.2, C28.1, C30.2, C31.2, C33.1, C34.1, C36.2, C38.2, C39.2, C41.2, C_adc1.2, C_env1.2, Cbuck1.2, Cbuckout1.2, Csnub1.2, D1.1 (K), D3.1 (K), D4.2 (A), D5.2 (A), IC1.4 (V-), IC2.4 (V-), J1.2 (Ext), J2.2 (Ext), J3.1, J6.1, J7.1, J8.2, J9.1, J9.3, J9.19, J10.2, J10.3, J10.6, J11.2, J11.8, J12.3, J12.6, J13.A1 (GND), J13.A12 (GND), J13.B1 (GND), J13.B12 (GND), J13.SH (SHIELD), J14.2, J15.2, J15.8, LED_stat1.1 (K), R5.2, R17.2, R18.2, R19.2, R22.2, R26.1, R29.2, R31.2, R37.1, R39.2, R_env1.2, SW_boot1.2, SW_reset1.2, U1.1 (GND), U1.40 (GND), U1.41 (GND), U2.3 (GND), U2.5 (~ON/OFF), U3.1 (GND), U4.4 (DGND), U4.9 (AGND)
unnamed: C27.1, R32.2
unnamed: Csnub1.1, Rsnub1.2
unnamed: D2.2 (A), IC2.7 (OUTB), R27.2
unnamed: D4.1 (K), L1.2, Rsnub1.1, U2.4 (OUT)
unnamed: D6.2 (A), J13.A4 (VBUS), J13.A9 (VBUS), J13.B4 (VBUS), J13.B9 (VBUS)
unnamed: D7.1 (A), Q1.4, R5.1
unnamed: D7.3 (K), J14.1, Q1.1, Q1.2, Q1.3
unnamed: F1.1, Q1.5, Q1.6, Q1.7, Q1.8
unnamed: C35.2, IC1.3 (+INA), IC1.5 (+INB), R38.2, R39.1
unnamed: IC1.2 (-INA), R33.2, R37.2
unnamed: IC1.6 (-INB), IC1.7 (OUTB)
unnamed: IC1.1 (OUTA), R32.1, R33.1
unnamed: C20.2, IC2.3 (+INA), R28.2, R29.1
unnamed: C21.2, IC2.5 (+INB), R21.2, R22.1
unnamed: IC2.2 (-INA), R26.2, R35.1
unnamed: IC2.6 (-INB), R27.1, R31.1
unnamed: J2.1 (In), R_in1.1
unnamed: J10.4, J12.4, R_PDN_UP1.1, R_UART1.2
unnamed: J12.2, R12.2
unnamed: J13.A5 (CC1), R17.1
unnamed: J13.B5 (CC2), R18.1
unnamed: LED_stat1.2 (A), R6.1
unnamed: C10.1, R40.1, SW_reset1.1, U1.3 (EN)
unnamed: C41.1, R41.1, SW_boot1.1, U1.27 (IO0)
unnamed: C30.1, U4.3 (CAP/2.5V)
unnamed: C34.2, U4.1 (COMP)

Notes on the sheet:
stage 1 set gain to 4.9
pre ADC processing
HF/LF power decoupling
AD9833 Signal Gen
HF/LF power decoupling
v2.5
RX Chain
UART address: 0
ESP 32 S3 N8
note: only channel 1 is used channel 2 is kept stable by setting it as a unity gain follower
TMC2209 #2 Header Pins
RX input protection
envelope rectifier diode
EMBO MCU Board v1.0
envelope RC
AC coupling (blocks DC)
pre ADC filter (rec by espressif)
internal voltage reference (data sheet requirement)
TMC2209 #1 Header Pins
VDD3P3_RTC pin
stage 1 set gain to 10.1
LDO 5V to 3V3
unity gain follower (tie off the unused channel)
catch diode
TL matching (reflected wave dampener)
snubber (damp HF)
VDD3P3 pin 1
1.65V bias
stage 2 set gain to 10.1
to motor coils
01/07/2026
24V to 5V Buck Converter
Boot Circuit
RX amplifier
Micro-controller
TX Chain
TX amplifier
clamps voltage transients above 28V
switching inductor
power decoupling

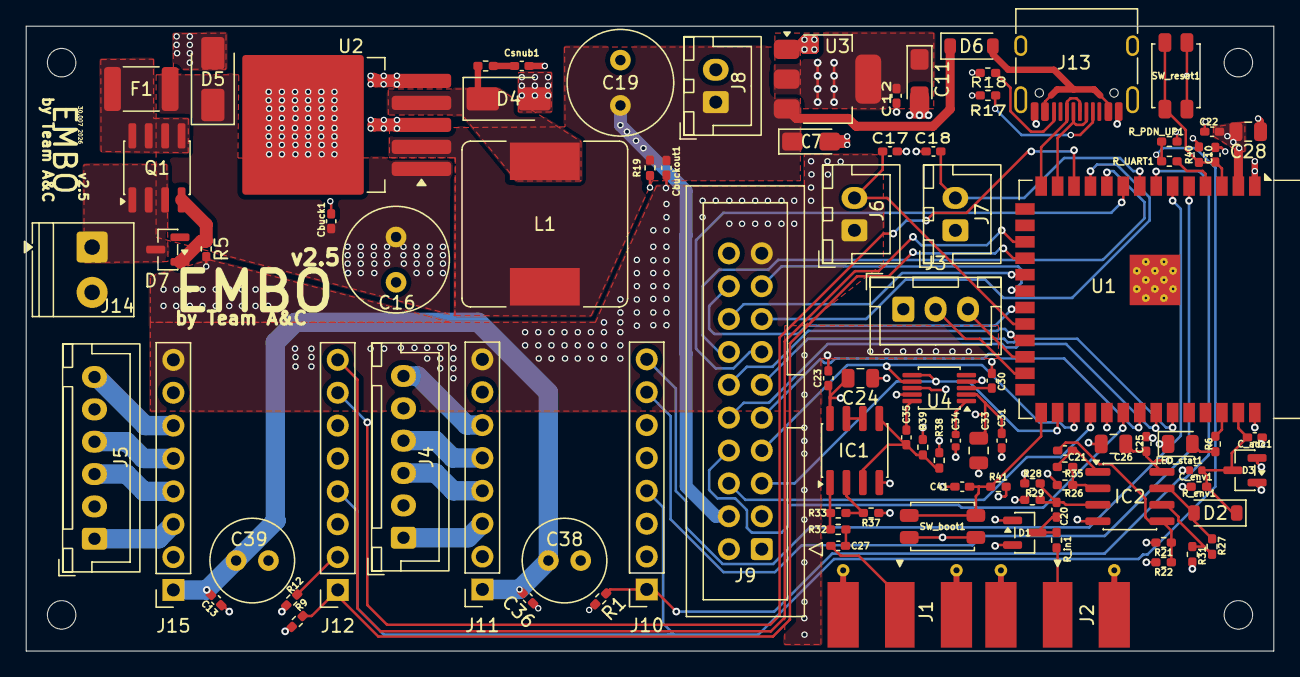
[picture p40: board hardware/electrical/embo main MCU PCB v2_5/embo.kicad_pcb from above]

Board: 4 copper layers, 96.4 x 48.3 mm, 94 parts (0 on the bottom side), 72 nets.

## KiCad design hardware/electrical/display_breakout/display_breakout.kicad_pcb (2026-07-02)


Board: 2 copper layers, 126.0 x 62.5 mm, 18 parts (1 on the bottom side), 19 nets, no tracks yet.

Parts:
BZ1: Buzzer; Buzzer_12x9.5RM7.6
C1, C2, C3, C4, C5: 100nF; C_0603_1608Metric
J1: Conn_02x10_Odd_Even; IDC-Header_2x10_P2.54mm_Vertical
J2: Conn_01x14_Socket; PinSocket_1x14_P2.54mm_Vertical
Q1: 2N7002; SOT-23
R2, R3, R4, R5, R6, R7: 10k; R_01005_0402Metric
SW1: RotaryEncoder_Switch; RotaryEncoder_Alps_EC11E-Switch_Vertical_H20mm
SW2, SW3: SW_Push; SW_TH_Tactile_Omron_B3F-100x

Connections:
+3.3V: J1.2, J2.7, J2.14, R3.2, R4.2, R5.2, R6.2, R7.2
+5V: BZ1.1 (+), J1.4
/BTN1: C4.1, J1.16, R6.1, SW2.1
/BTN2: C5.1, J1.17, R7.1, SW3.1
/BUZ_PWM: J1.18, R2.2
/EC11_A(CLK): C1.1, J1.13, R3.1, SW1.A
/EC11_B (DT): C2.1, J1.14, R4.1, SW1.B
/EC11_SW: C3.1, J1.15, R5.1, SW1.S1
/SPI_CLK: J1.7, J2.5, J2.8
/SPI_MISO: J1.6, J2.2, J2.6
/SPI_MOSI: J1.5, J2.3, J2.9
/TFT_CS: J1.8, J2.12
/TFT_DC: J1.9, J2.10
/TFT_RST: J1.10, J2.11
/TOUCH_CS: J1.11, J2.4
/TOUCH_IRQ: J1.12, J2.1
GND: C1.2, C2.2, C3.2, C4.2, C5.2, J1.1, J1.3, J1.19, J1.20, J2.13, Q1.2 (S), SW1.C, SW1.S2, SW2.2, SW3.2
unnamed: BZ1.2 (-), Q1.3 (D)
unnamed: Q1.1 (G), R2.1

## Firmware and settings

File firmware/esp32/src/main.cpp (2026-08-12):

#include <Arduino.h>
#include "esp_log.h"
#include "config.h"
#include "data_logger.h"
#include "motors.h"
#include "uas.h"
#include "turbidity.h"
#include "force_sensor.h"
#include "calibration.h"
#include "ui.h"
#include "rpi_uart.h"
#include "ble_debug.h"
#include "scheduler.h"

void setup() {
    Serial.begin(115200);
    Serial.println("BOOT: starting");

    // Silences the "E (...) i2c.master: ..." spam from the turbidity bus
    // (expected/benign if those sensors aren't physically connected — see
    // turbidity.cpp's retry logic) at the source, rather than needing to
    // grep it out of the serial log afterward. Doesn't affect anything
    // else's logging (targeted at this one driver tag), and doesn't
    // change turbidity_update()'s actual retry behavior at all — this is
    // purely cosmetic, quieting the console.
    esp_log_level_set("i2c.master", ESP_LOG_NONE);

    data_logger_init();
    Serial.println("BOOT: data_logger_init done");

    motors_init();
    Serial.println("BOOT: motors_init done");
    uas_init();
    Serial.println("BOOT: uas_init done");
    // Re-enabled for the BLE telemetry dashboard (Optical Sensor 1/2 cards)
    // — safe regardless of SENSOR_CAL_TABLE's fill state: every fusion
    // channel in that table (calibration.cpp) is still placeholder zeros,
    // so calib_estimate_particle_size_um()'s monotonicity gate already
    // excludes turbidity (and everything else) from the mixing/scheduler
    // math either way. This only feeds live readings to the dashboard; it
    // does not change scheduler.cpp's behavior. If the sensors are ever
    // physically disconnected again, turbidity_update()'s own retry/backoff
    // logic handles that gracefully (see turbidity.cpp) — no I2C error spam,
    // just a "not found" badge on the dashboard.
    turbidity_init();
    Serial.println("BOOT: turbidity_init done");
    force_sensor_init();   // fusion input AND independent e-stop safety input, see calibration.h
    Serial.println("BOOT: force_sensor_init done");
    force_sensor_tare(); //fresh zero after every boot
    Serial.println("BOOT: force_sensor_tare done");
    ui_init();
    Serial.println("BOOT: ui_init done");
    rpi_uart_init();
    Serial.println("BOOT: rpi_uart_init done");
    ble_debug_init();
    Serial.println("BOOT: ble_debug_init done (BLE off by default — enable via Settings > Developer mode > UAS debug mode)");
    scheduler_init();
    Serial.println("BOOT: scheduler_init done");

    // Deliberately NOT homing here. Startup only brings hardware/UI up —
    // homing can still be done explicitly beforehand (Settings > Motion >
    // Home Motors, the Mixing Menu's own homing gate, or the BLE `HOME`
    // command), but it's no longer required before starting a mix:
    // scheduler_start() (scheduler.cpp) auto-homes itself if needed, and
    // fails cleanly (surfaced as a fault screen from warning_screen.cpp)
    // if that auto-home doesn't succeed — there's still no path to
    // running un-homed.
    Serial.println("BOOT: setup() complete, entering loop() (not homed yet — home from the UI or BLE, or it'll auto-home on mixing start)");

    // Load cell data over Serial, ~20Hz — see the CSV header printed once
    // in setup(). Deliberately NOT gated on BLE/ble_log() at all, unlike
    // everything else in this file — the point is to have this work even
    // if BLE is completely disconnected or misbehaving. Converted to
    // grams via calib_hx711_to_grams() (real measured scale factors, see
    // calibration.h) — not raw counts.
    Serial.println("LC,millis_ms,grams1,grams2");
}

void loop() {
    rpi_uart_update();
    uas_update();
    turbidity_update();  // see setup()'s comment — feeds the BLE telemetry dashboard, not scheduler fusion

    // force_sensor_update() still runs every loop — it's still one of the
    // four fusion inputs the scheduler uses for size estimation (see
    // scheduler.h/calibration.h). The automatic load-cell e-stop that used
    // to trigger scheduler_emergency_stop() based on force_sensor_estop_tripped()
    // has been deliberately removed — force_sensor_estop_tripped() and
    // HX711_ESTOP_GRAMS (calibration.h) still exist but nothing calls them
    // anymore. No automatic overforce/jam protection remains; BTN1 (held
    // >=800ms) is a manual e-stop only, requiring an operator to act.
    force_sensor_update();

    // Load cell data over Serial, ~20Hz — see the CSV header printed once
    // in setup(). Deliberately NOT gated on BLE/ble_log() at all, unlike
    // everything else in this file — the point is to have this work even
    // if BLE is completely disconnected or misbehaving.
    static uint32_t lastForcePrintMs = 0;
    if (millis() - lastForcePrintMs >= 50) {
        lastForcePrintMs = millis();
        float grams1 = calib_hx711_to_grams(0, force_sensor_get_raw_1());
        float grams2 = calib_hx711_to_grams(1, force_sensor_get_raw_2());
        Serial.printf("LC,%lu,%.2f,%.2f\n", millis(), grams1, grams2);
        data_logger_log(millis(), grams1, grams2);  // no-op unless a BLE-triggered capture session is active
    }

    ui_update();
    ble_debug_update();
    scheduler_update();
}

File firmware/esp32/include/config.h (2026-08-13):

#pragma once

#include <cstdint>

// ── Firmware version ─────────────────────────────────────────────────────────
#define FIRMWARE_VERSION "0.7.6"

// ── GPIO assignments (EMBO v3.4) ─────────────────────────────────────────────
// Source: docs/EMBO_PCB_Design_Brief_v3_4.txt, docs/EMBO_Pinout_Cheatsheet.txt
// CHANGED FROM v2.4: GPIO21/37/42 used to be touch pins — they are now HX711
// load-cell pins (added v3.2). Touch moved to GPIO12/46 in v3.3. TMC UART is
// now two separate pins (GPIO4 TX / GPIO44 RX), not one bidirectional pin.

// UAS / ADC
#define PIN_UAS_ADC         1   // ADC1_CH0 — envelope detector output

// Status LED
#define PIN_STATUS_LED      2

// I2C turbidity bus — APDS9960 (0x39, ALS) + MAX30102 (0x57, backscatter)
#define PIN_I2C_SDA         3
#define PIN_I2C_SCL         43
#define I2C_CLOCK_HZ        400000
#define APDS9960_ADDR       0x39
#define MAX30102_ADDR       0x57
// A transient I2C glitch shouldn't permanently drop a channel out of
// fusion for the rest of a run — retry re-init at this cadence while a
// device is marked not-ok. See turbidity.cpp.
#define TURBIDITY_REINIT_INTERVAL_MS  2000

// Syringe-presence note on WarningScreen (UI hint only — never gates
// starting a run). APDS9960 clear channel (fixed 4x gain, no
// auto-exposure) reads HIGHER once a syringe is mounted (not lower —
// corrected after an initial wrong assumption). Simple single-baseline
// delta (first sample taken on this screen visit vs. current) — known to
// be vulnerable to ambient light drift between baseline and check, being
// tried anyway for comparison against a rolling-window approach. See
// warning_screen.cpp.
#define SYRINGE_DETECT_RISE_COUNTS       100
#define SYRINGE_DETECT_SAMPLE_INTERVAL_MS 50

// Motor driver — shared PDN_UART bus, genuinely separate TX/RX pins
#define PIN_TMC_UART_TX     4
#define PIN_TMC_UART_RX     44

// Motor 1 (TMC2209 U5/SK1, UART addr set via MS1/MS2 jumpers)
#define PIN_STEP_M1         5
#define PIN_DIR_M1          6
#define PIN_EN_M1           7

// Motor 2 (TMC2209 U6/SK2)
#define PIN_STEP_M2         8
#define PIN_DIR_M2          9
#define PIN_EN_M2           10

// UI buttons (via IDC ribbon)
#define PIN_BTN1            11  // dedicated stop/e-stop button — see ui.h
// GPIO12 = T_CS (touch), not a button as of v3.3 — see below
#define PIN_BUZ_PWM         13  // LEDC PWM → buzzer

// Limit switches
#define PIN_LIMIT_M1        14
#define PIN_LIMIT_M2        15

// EC11 rotary encoder (via IDC ribbon)
#define PIN_EC11_A          16
#define PIN_EC11_B          17
#define PIN_EC11_SW         18

// USB (fixed PHY — do not reassign)
// GPIO19 = USB D−, GPIO20 = USB D+

// Load cells — HX711 x2, shared clock (added v3.2)
#define PIN_HX711_2_DT      21  // CHANGED v3.2: was TOUCH_IRQ pre-v3.2
#define PIN_HX711_SCK       37  // CHANGED v3.2: was SPI_MISO pre-v3.2, shared between both modules
#define PIN_HX711_1_DT      42  // CHANGED v3.2: was TOUCH_CS pre-v3.2

// SPI bus (shared: ILI9341, XPT2046 touch, AD9833) — no MISO on this bus as
// of v3.2 (touch MISO/T_DO moved to GPIO46, see below); AD9833 has no MISO.
#define PIN_SPI_MOSI        35
#define PIN_SPI_CLK         36

// SPI chip selects
#define PIN_AD9833_CS       38  // AD9833 FSYNC — SPI Mode 2
#define PIN_TFT_CS          39  // ILI9341 CS   — SPI Mode 0
#define PIN_TFT_DC          40
#define PIN_TFT_RST         41

// Touch (XPT2046), restored v3.3 on the two remaining strapping pins with
// headroom — see design brief §8.3 for the rationale. T_IRQ is NOT wired on
// the main board; touch is polled instead. A touch integration attempt was
// made and reverted after it caused a boot hang — see LGFX_Config.h's
// TOUCH_TODO comment for what to restore once that's debugged on real
// hardware. Currently unused.
#define PIN_TOUCH_CS        12  // T_CS
#define PIN_TOUCH_DO        46  // T_DO (MISO)

// RPi UART (UART1)
#define PIN_RPI_TX          47
#define PIN_RPI_RX          48

// ── SPI clock speeds ─────────────────────────────────────────────────────────
#define SPI_CLK_TFT         20000000   // 20 MHz max via IDC ribbon
#define SPI_CLK_TOUCH        2000000   // 2 MHz (XPT2046 max) — currently unused, see PIN_TOUCH_CS above
#define SPI_CLK_AD9833      10000000   // ~10 MHz — short direct trace

// ── UART speeds ───────────────────────────────────────────────────────────────
#define BAUD_RPI            921600
#define BAUD_TMC            115200

// ── TMC2209 UART addresses ────────────────────────────────────────────────────
// Field-jumpered as of v3.4 (JMP_MS1_Tn/JMP_MS2_Tn) — these values are the
// jumper positions currently populated, not hardwired straps.
#define TMC_ADDR_M1         0   // MS1=GND, MS2=GND
#define TMC_ADDR_M2         1   // MS1=3.3V via 10k, MS2=GND
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

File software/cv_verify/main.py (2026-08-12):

"""cv_verify entry point — on-demand, single-shot CV verification.

Replaces ../cv-pipeline/main.py's free-running "capture every 0.1s and
stream" loop with a request/reply loop: idle (sending nothing) until the
ESP32 sends "CAPTURE", then capture one frame, attempt detection+sizing,
and reply. See TODO.md Layer 1 and link.py's module docstring for the wire
protocol.

detection.py/sizing.py are intentionally NOT duplicated here — they're
loop/trigger-agnostic (see TODO.md's closing note), so this imports them
straight from ../cv-pipeline. Both now call Roboflow's hosted Serverless
Cloud API (PoC — local/offline inference is blocked on the current
Roboflow plan, see cv-pipeline/detection.py's module docstring); this loop
still degrades to a status string instead of crashing on "no particles
found" or a network/API error, same as when they were stubs.
"""
import sys
import time
from pathlib import Path

import serial
from PIL import Image

# ../cv-pipeline holds detection.py/sizing.py — see module docstring above
# for why these are imported rather than copied. Appended, not inserted at
# index 0 — cv-pipeline has its own config.py, and this folder's own
# modules (including config.py) must resolve first, not be shadowed by it.
sys.path.append(str(Path(__file__).resolve().parent.parent / "cv-pipeline"))

import config
from capture import Camera
from link import FirmwareLink
from preprocessing import enhance_for_display
from detection import ParticleDetector, draw_overlay  # from ../cv-pipeline
from sizing import compute_ecd_stats                   # from ../cv-pipeline

POLL_INTERVAL_S = 0.05  # link.py's readline() already timeouts at 0.1s; this just avoids a tight spin


def handle_capture(camera: Camera, link: FirmwareLink, detector: ParticleDetector) -> None:
    """One capture-and-reply cycle. Must complete well inside
    config.CAPTURE_TIMEOUT_S — see link.py's module docstring.
    """
    started = time.monotonic()

    # Median-stack (cancels sensor noise) + flat-field + clarity boost
    # (removes the glare gradient, then locally boosts what contrast is
    # left) before detection — validated interactively against real
    # low-contrast frames during bring-up, see config.py's Preprocessing
    # section. Not optional polish: the open-top syringe mount caps how
    # far dark-field lighting alone can go, so software has to make up the
    # rest of the gap.
    raw = camera.read_frame_stack()
    if raw is None:
        link.send_status("CV: bad frame, capture aborted")
        return
    frame = enhance_for_display(raw)

    # Saved unconditionally, independent of whether detection below
    # succeeds — this is the plain (non-annotated) capture, useful for
    # debugging on the Pi even when the transmitted preview ends up
    # blob-annotated or detection fails outright.
    full_res_image = Image.fromarray(frame)
    try:
        full_res_image.save(config.LAST_CAPTURE_IMAGE_PATH)
    except OSError as e:
        print(f"WARNING: could not save processed image: {e}", file=sys.stderr)

    # Run detection BEFORE sending the preview image, so the transmitted
    # photo can have segmentation blob outlines baked in (see
    # verifying_screen.cpp's two-column image+result layout) — the
    # firmware displays whatever bytes arrive as-is, it doesn't know about
    # polygons itself.
    masks = []
    stats = None
    try:
        masks = detector.detect(frame)
        # UM_PER_PIXEL measured 2026-08-08 against a ruler at the working
        # distance — see config.py's Pixel-to-micron calibration section
        # for the measurement and its caveats (rough bench value, not the
        # formal Track 1 validation from master_experiment1_validation_protocol.md).
        stats = compute_ecd_stats(masks, um_per_pixel=config.UM_PER_PIXEL)
    except ValueError:
        # "No particles detected/sized" is a normal outcome (e.g. an empty
        # syringe view), not a crash — firmware's verifying_screen already
        # renders a "no size data" placeholder when no SIZE line arrives.
        link.send_status("CV: no particles detected")
    except Exception as e:
        # Roboflow API/network errors, malformed responses, etc. — must
        # not kill the on-demand loop; report and let firmware show its
        # own placeholder rather than a hard TIMED_OUT for a problem that
        # isn't actually a timeout.
        print(f"WARNING: detection/sizing failed: {e}", file=sys.stderr)
        link.send_status("CV: detection failed")

    overlay_image = draw_overlay(full_res_image, masks) if masks else full_res_image
    try:
        preview = overlay_image.resize(
            (config.IMG_TRANSFER_W, config.IMG_TRANSFER_H), Image.LANCZOS
        )
        link.send_image(config.IMG_TRANSFER_W, config.IMG_TRANSFER_H, preview.tobytes())
    except (OSError, serial.SerialException) as e:
        print(f"WARNING: could not send preview image: {e}", file=sys.stderr)

    if stats is not None:
        link.send_size(stats.median_um, stats.iqr_um)

    elapsed = time.monotonic() - started
    if elapsed > config.CAPTURE_TIMEOUT_S * 0.8:
        # Not a hard failure (firmware doesn't hear about this), but a loud
        # local warning — getting close to RPI_CAPTURE_TIMEOUT_MS is worth
        # knowing about before it starts actually timing out intermittently.
        print(f"WARNING: capture+reply took {elapsed:.2f}s, "
              f"budget is {config.CAPTURE_TIMEOUT_S:.2f}s", file=sys.stderr)


def main():
    camera = Camera()
    link = FirmwareLink()
    detector = ParticleDetector(config.WEIGHTS_PATH)

    link.send_status("CV: init OK, waiting for CAPTURE")

    try:
        while True:
            if link.wait_for_capture_request():
                handle_capture(camera, link, detector)
            else:
                time.sleep(POLL_INTERVAL_S)
    except KeyboardInterrupt:
        pass
    finally:
        camera.release()
        link.close()


if __name__ == "__main__":
    main()

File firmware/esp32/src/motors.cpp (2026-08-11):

#include "motors.h"
#include "config.h"
#include "ble_debug.h"
#include "force_sensor.h"
#include <Arduino.h>
#include <TMCStepper.h>
#include <esp_timer.h>
#include <cstdint>

// Half-duplex UART for both TMC2209 modules on the shared PDN line.
// Serial1 is used; TX (GPIO4) and RX (GPIO44) are genuinely separate ESP32
// pins as of v3.4, both wired to the same physical PDN_UART bus node via
// R_UART (1kΩ) + R_PDN_UP (10kΩ pull-up) on the main board — a same-pin
// shared TX/RX config was tried first and proved unreliable, see
// docs/EMBO_PCB_Design_Brief_v3_4.txt §7.3.
static HardwareSerial _tmc_serial(1);
static TMC2209Stepper _driver_m1(&_tmc_serial, TMC_R_SENSE, TMC_ADDR_M1);
static TMC2209Stepper _driver_m2(&_tmc_serial, TMC_R_SENSE, TMC_ADDR_M2);

static volatile bool _limit_m1_hit = false;
static volatile bool _limit_m2_hit = false;

static bool     _homed        = false;
static uint32_t _stroke_count = 0;

// ── Step generation: hardware timer (esp_timer), ISR-ticked, one pulse per
// callback — ported from a confirmed-working bench firmware
// (PCB_Test_Firmware_v3_4) after the previous LEDC PWM-based driver here
// could not move the motors at all. Root cause turned out to be upstream
// in the TMC2209 init sequence (missing toff/pdn_disable/senddelay, see
// _tmc_init_driver below), not the step-generation mechanism itself — but
// this port keeps the whole confirmed-working sequence together rather
// than mixing a validated init with an unvalidated pulse generator.
// Bonus: position is now an exact ISR-incremented step count, not a
// time-integrated estimate — see motor_get_position()/motor_reset_position().
struct StepAxis {
    int stepPin, dirPin, enPin;
    volatile int8_t  dir      = 0;  // -1 / 0 / +1 — 0 means stopped
    volatile int32_t position = 0;  // exact, ISR-incremented step count
    volatile int32_t softMin  = INT32_MIN;  // disabled by default — see motor_set_soft_limits()
    volatile int32_t softMax  = INT32_MAX;
    esp_timer_handle_t timer  = nullptr;
};
static StepAxis _axis1{PIN_STEP_M1, PIN_DIR_M1, PIN_EN_M1};
static StepAxis _axis2{PIN_STEP_M2, PIN_DIR_M2, PIN_EN_M2};

static StepAxis &_axis(uint8_t motor) { return (motor == 1) ? _axis1 : _axis2; }

static void IRAM_ATTR _stepPulse(void *arg) {
    StepAxis *ax = static_cast<StepAxis *>(arg);
    if (ax->dir == 0) return;  // defensive — esp_timer_stop() is what actually prevents firing
    int32_t nextPos = ax->position + ax->dir;
    if (nextPos < ax->softMin || nextPos > ax->softMax) {
        // Would cross a configured soft limit — stop right here, don't
        // take this step. Reversing direction and re-issuing speed moves
        // back away from the limit normally; this only blocks the
        // direction that would go further past it.
        esp_timer_stop(ax->timer);
        ax->dir = 0;
        return;
    }
    digitalWrite(ax->stepPin, HIGH);
    delayMicroseconds(2);
    digitalWrite(ax->stepPin, LOW);
    ax->position = nextPos;
}

void IRAM_ATTR isr_limit_m1() {
    _limit_m1_hit = true;
    // Immediately silence stepping so the motor stops within one step.
    esp_timer_stop(_axis1.timer);  // safe even if not currently running
}

void IRAM_ATTR isr_limit_m2() {
    _limit_m2_hit = true;
    esp_timer_stop(_axis2.timer);
}

static void _tmc_init_driver(TMC2209Stepper &drv, uint8_t addr) {
    drv.begin();

    // TOFF=0 explicitly disables the TMC2209's driver output stage — a
    // hardware fact about this chip, not a library default to trust.
    // Without this, STEP pulses can arrive with EN correctly asserted and
    // the motor still never produces torque. This was the actual root
    // cause of "no movement at all" — confirmed by comparing against
    // PCB_Test_Firmware_v3_4, a bench firmware that moves these same
    // modules correctly and always sets this.
    drv.toff(4);

    // Real calibrated current via TMCStepper's own rms_current() (which
    // does the IHOLD/IRUN register math from actual mA figures using
    // TMC_R_SENSE), not hand-picked raw register values.
    drv.rms_current(TMC_RUN_CURRENT_MA, (float)TMC_HOLD_CURRENT_MA / (float)TMC_RUN_CURRENT_MA);

    // PDN_UART is a multiplexed pin on this chip — without this, it can be
    // misread as an external power-down signal instead of pure UART
    // traffic. Matters more than usual here since both modules share one
    // PDN_UART bus (multi-drop, see EMBO_PCB_Design_Brief_v3_4.txt §7.3).
    drv.pdn_disable(true);

    // Use UART-controlled current scaling, not the onboard trimpot.
    drv.I_scale_analog(false);

    // SpreadCycle is required for StallGuard4. This module has no SPREAD pin —
    // must be set via UART at every boot. Read back to confirm before proceeding.
    drv.en_spreadCycle(true);
    bool sc = drv.en_spreadCycle();
    if (!sc) {
        ble_log("TMC addr %u: SpreadCycle write FAILED — SG data unreliable", addr);
    } else {
        ble_log("TMC addr %u: SpreadCycle OK", addr);
    }

    // Multi-drop UART bus timing — the TMC2209 datasheet specifically
    // calls for SENDDELAY >= 2 "in a multiple node system... to ensure
    // clean bus transitions," and that's exactly this board's topology
    // (2 drivers, 1 shared PDN_UART bus).
    drv.senddelay(4);

    // 8 microsteps: good balance of resolution and StallGuard sensitivity.
    // StallGuard becomes less reliable above 16 microsteps at low speed.
    drv.microsteps(8);

    // Enable StallGuard across the full speed range.
    // SG_RESULT is only valid when TSTEP < TCOOLTHRS. Setting TCOOLTHRS to
    // max (0xFFFFF) means StallGuard is active at all motor speeds.
    drv.TCOOLTHRS(0xFFFFF);

    // Verify GCONF readback as a basic comms sanity check.
    uint32_t gconf = drv.GCONF();
    ble_log("TMC addr %u: GCONF=0x%08X", addr, gconf);

    // TMCStepper's own dedicated UART link-check — 0 = good connection,
    // non-zero = bad. More definitive than inferring from SpreadCycle
    // readback alone, since a corrupted read could coincidentally still
    // look like it "worked."
    uint8_t conn = drv.test_connection();
    ble_log("TMC addr %u: test_connection() = %u (%s)", addr, conn, conn == 0 ? "OK" : "BAD LINK");
}
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

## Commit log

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2026-06-27 kicad pcb file
    [embo.csv, embo.kicad_pcb, embo.kicad_sch]
2026-06-27 updated pcb schematic
    [embo.csv, embo.kicad_pcb, embo.kicad_sch]
2026-06-28 Move KiCad project folder under hardware/electrical
    [embo.csv, embo.kicad_pcb, embo.kicad_sch]
2026-06-28 schematic and pcb docs update
    [embo.kicad_pcb, embo.kicad_sch]
2026-06-29 update schematic and PCb docs
    [embo.kicad_sch]
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2026-06-29 PCB Placement Update
    [embo.kicad_pcb, embo.kicad_sch]
2026-06-30 Created display_breakout kicad file folder
    [display_breakout.kicad_pcb, display_breakout.kicad_sch]
2026-06-30 PCB layout update
    [embo.kicad_pcb, embo.kicad_sch]
2026-06-30 Updated breakout schematic
    [display_breakout.kicad_pcb, display_breakout.kicad_sch]
2026-06-30 included buzzer in schematic
    [display_breakout.kicad_sch]
2026-06-30 updated buzzer
    [display_breakout.kicad_sch]
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2026-06-30 updated schematic to latest version
    [display_breakout.kicad_pcb, display_breakout.kicad_sch]
2026-06-30 updated pcb layout
    [display_breakout.kicad_pcb]
2026-06-30 updated display_breakout pcb layout
    [display_breakout.kicad_pcb]
2026-06-30 main PCB layout update
    [embo.kicad_pcb, embo.kicad_sch]
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2026-06-30 Remove KiCad lock files and ignore *.lck globally
    Lock files are created by KiCad when a project is open and should never
    be committed. Added **/*.lck to .gitignore to prevent recurrence.
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2026-07-01 Fix KiCad temp files leaking into git
    - Broaden .gitignore to use **/*.kicad_prl so all subdirectories are covered
    - Untrack display_breakout.kicad_prl and embo.kicad_prl (workspace prefs only)
    - Teammate pull was blocked because display_breakout.kicad_prl was tracked
2026-07-01 Finish main PCB layout, starting routing
    [embo.kicad_pcb]
2026-07-01 PCB trace routing update 50%
    [embo.kicad_pcb, embo.kicad_sch]
2026-07-01 fix LM2596S-5 Buck Converter Footprint pinout mismatch and reroute buck converter block to minimise switching circuit loop area
    [embo.kicad_pcb, embo.kicad_sch]
2026-07-01 signal routing update 70%
    [embo.kicad_pcb]
2026-07-01 main PCB routing update 90%
    [embo.kicad_pcb]
2026-07-01 PCB main added EMI shield (heavily stitched GND plane) between buck - UAS block
    [embo.kicad_pcb]
2026-07-01 updated schematic for display_breakout
    [display_breakout.kicad_pcb, display_breakout.kicad_sch]
2026-07-02 fixed silkscreen on main PCB
    [embo.kicad_pcb]
2026-07-02 finish routing main PCB
    [embo.kicad_pcb]
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2026-07-02 main PCB DRC round 1
    [embo.kicad_pcb]
2026-07-02 added display_breakout_small
    [display_breakout.kicad_pcb, display_breakout_small.kicad_pcb, display_breakout_small.kicad_sch]
2026-07-02 added silkscreen team name and rounded pcb corners
    [display_breakout_small.kicad_pcb]
2026-07-02 main PCB finishing done
    [embo.kicad_pcb]
2026-07-02 added PCB STEP files
    [EMBO DISPLAY BREAKOUT.step]
2026-07-03 fix PCB reference errata -> v2.51
2026-07-03 added gerber files
    [display_breakout_small-B_Cu.gbr, display_breakout_small-B_Mask.gbr, display_breakout_small-B_Paste.gbr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]
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2026-07-03 added production files for pcbs
    [display_breakout_small.csv, display_breakout_small_R1_bom.csv, display_breakout_small_R1_designators.csv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]
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2026-07-07 loadcell testing code with working csv and graph output
    [test_20260707_163140.csv]
2026-07-09 reexported kicad step file
    [.step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]
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2026-07-09 loadcell baseline for syringe added (with graph)
    [test_20260709_123600.csv]
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2026-07-10 PCB test firmware and BLE html sensor and control interface
    [embo.kicad_sch]
2026-07-13 changed mcu to esp32s3, partially solved banding refresh issues
    [config.h, encoder_driver.cpp, main.cpp]
2026-07-14 added another syringe test, modified display code
    [test_20260709_123600 (baseline lyostypt).csv, test_20260714_180203 (china foam big).csv]
2026-07-15 plot graph for syringe loadcell test
    [test_20260714_185031 (china foam small.csv]
2026-07-16 updated new PCB doc and folder names
    [embo-B_Cu.gbr, embo-B_Mask.gbr, embo-B_Paste.gbr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]
2026-07-17 MCU PCB v3.4 schematic and routing update
    [embo.csv, embo.kicad_pcb, embo.kicad_sch]
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2026-07-17 finish PCB v3.4 routing
    [embo.kicad_pcb, embo.kicad_sch]
2026-07-18 v3.4 PCb final changes
    [embo.kicad_pcb, embo.kicad_sch]
2026-07-18 updates readmes and docs for PCB v3.4
    [embo.kicad_pcb]
2026-07-20 all small breakout PCBs: Limit Switch, 2x Backup Sensors
    [APDS9960.kicad_pcb, APDS9960.kicad_sch, EMBO MAIN PCB v3.4.step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]
2026-07-21 backup sensor and limit switch PCBs
    [APDS9960-B_Cu.gbr, APDS9960-B_Mask.gbr, APDS9960-Edge_Cuts.gbr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]
2026-07-23 added buzzer drivers
    [embo main MCU PCB.step]
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2026-07-26 updated variablenames for pins and minor bug fixes
    [button_driver.h, main.cpp]
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2026-08-01 Add UAS frequency sweep test rig
    [2.20 V .csv, 2.20 V.csv, 2.20 v .csv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]
2026-08-03 Add gain-tuning test data (10x/26x/50x/102x) and oscilloscope cross-check
    [RX side.csv, TX side.csv, uas_averaged_summary_2026-08-01T08-27-21-358Z.csv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]
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2026-08-03 Add stroke 0/1/5/10 particle sizing data, summary, and trend graph
    [2dmeasure - 1.csv, 2dmeasure - 10.csv, 2dmeasure - 11.csv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]
2026-08-04 fixed bluetooth uas data collection, added new ui menus (still need refining)
    [ui.cpp]
2026-08-05 fixed agent selection screen
    [ui.cpp]
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2026-08-05 Add stroke 15/20 data, update summary table, trend graph, and README
    [2dmeasure - 1.csv, 2dmeasure - 10.csv, 2dmeasure - 11.csv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]
2026-08-06 changed menu colours and attempted motor homing fix
    [motors.cpp]
2026-08-06 tried to fix motor movement issue
    [buzzer_driver.cpp, config.h, motors.cpp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]
2026-08-06 fixed motor movement backend
    [config.h, motors.cpp]
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2026-08-07 fix for motor homing and limits
    [motors.cpp]
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2026-08-07 Add stroke 25 data and variance study results
    [2dmeasure -8.csv, 2dmeasure - 1.csv, 2dmeasure - 10.csv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]
2026-08-07 motor syncing added to firmware, added loadcell data (uncleaned)
    [1 stroke.csv, 3 strokes stroke 1.csv, 3 strokes strokes 2 and 3.csv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]
2026-08-07 cleaned a little of loadcell data, added readme.md for loadcell data processing
    [1 stroke.csv, 1s.csv, 3 strokes stroke 1.csv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]
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2026-08-10 v0.6.4 fw and loadcell functionality test data
    [loadcellfunctionalitytest.csv]
2026-08-10 newer v0.6.5, very minor bug fix
    [config.h, ui.cpp]
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2026-08-11 new loadcell with acceleration test file
    [loadcell test w acceleration.csv]
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2026-08-11 updated v0.6.6 and added new loadcell data
    [1 stroke.csv, 11s1.csv, 11s2.csv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]
2026-08-12 rpi UART edits on firmware
    [ui.cpp.diff.txt]
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2026-08-12 loadcell mixing loop data
    [mixingloop1.csv, mixingloop2.csv, mixingloop3.csv]
2026-08-12 Fix Roboflow inference for Python 3.13 (Pi's fresh OS image)
    inference-sdk has no release compatible with Python 3.13, which this
    Pi's reflashed OS ships. Switch detection.py to a plain requests
    multipart POST against Roboflow's REST endpoint instead — same
    response shape, no SDK version constraint.
    [11s1.csv, 11s2.csv, 11s3.csv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]
2026-08-12 Restore testing/loadcell_viscosity/ accidentally deleted in 18ace27
    Those files were staged for deletion in the index from earlier
    Windows-can't-materialize-trailing-space-path troubleshooting this
    session, and got swept into an unrelated commit by mistake. Restored
    via index-only git read-tree (core.protectNTFS=false) since this
    directory still can't be checked out to a Windows working tree.
    [11s1.csv, 11s2.csv, 11s3.csv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]
2026-08-12 Re-enable turbidity sensors, redesign BLE dashboard as Telemetry Dashboard
    - main.cpp: turbidity_init()/update() back on for live optical sensor
    readings. Confirmed safe — SENSOR_CAL_TABLE is still all-placeholder
    zeros for every fusion channel, so scheduler mixing math already
    excludes turbidity regardless; this only feeds the dashboard.
    - web dashboard: retitled as Telemetry Dashboard, APDS9960/MAX30102
    relabeled Optical Sensor 1/2 (MAX30102's IR+Red channels merged into
    one card), removed SG_RESULT display from motor cards (jog/home
    controls kept).
    [main.cpp]
2026-08-12 Update README for Week 13/13: real CV/turbidity architecture, new PCB routing image
    - Week 11 -> 13 of 13, timeline table marked complete through Final Exhibition
    - Swapped KiCad editor screenshot for the trace routing view (L1+L4)
    - CV section rewritten: Pi Zero 2W + OV9281 + Roboflow-hosted RF-DETR
    on-demand verification (not Pi 5 + YOLOv8 continuous feed) — CV and
    turbidity are both explicitly non-fusion inputs today, only UAS
    drives the closed loop
    - Firmware status table: scheduler.cpp replaces the removed pid.cpp,
    LovyanGFX not TFT_eSPI, added turbidity + binary telemetry rows
    - Repo structure: cv_verify marked current, cv-pipeline marked legacy
    - Added Telemetry Dashboard se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
2026-08-13 Add syringe-presence hint to WarningScreen via Optical Sensor 1
    UI note only, never gates starting a run. Baseline-on-entry vs. current
    APDS9960 clear-channel reading; syringe mounted reads ~100+ counts
    higher than baseline (measured empirically, direction corrected from
    an initial wrong assumption). Threshold/sample-interval tunable via
    SYRINGE_DETECT_* in config.h.
    [config.h]
2026-08-16 Add Fusion 360 top-level assembly file, update mechanical + root READMEs
    [Final Pure Assembly.f3z]
